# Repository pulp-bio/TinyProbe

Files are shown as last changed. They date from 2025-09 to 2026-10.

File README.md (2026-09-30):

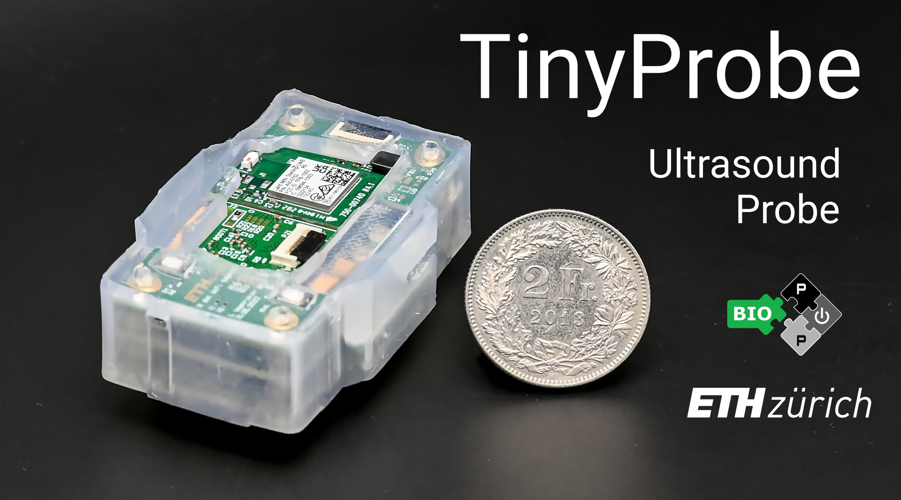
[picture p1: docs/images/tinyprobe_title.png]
TinyProbe main


# TinyProbe

A Wearable 32-Channel Multi-Modal Wireless Ultrasound Probe

## Introduction

This repository contains ongoing work on **TinyProbe**, an advanced wearable ultrasound platform developed at the [Integrated Systems Laboratory (IIS)](https://iis.ee.ethz.ch/) of ETH Zurich.

### Transmit

- **64 V peak-to-peak** bipolar excitations
- **32 pattern profiles** (fully programmable)
- **16 delay profiles** (fully programmable)

### Receive

- **21, 18, or 15 dB** low-noise amplifier (programmable)
- **21, 24, or 27 dB** programmable gain amplifier (PGA)
- **Up to 36 dB TGC** (fully programmable)
- **32 channels** (simultaneously sampled at up to **30 MSps, 10 bit**)

### Connectivity

Wi-Fi 6 link, data rates up to **35.7 Mbps**

### Operating Modes

1. **A-mode**, **B-mode**, **M-mode** with 32 channels (**175 FPS with Wi-Fi 6**, 32 channels, 400 samples per channel)
2. **Doppler mode** with 2 channels (**1500 FPS**)
3. **Raw RF data streaming** (**55 FPS**, 32 channels, 2000 samples per channel, 10 bit per sample)

The system design is described in detail in our publications in the [IEEE Transactions on Ultrasonics, Ferroelectrics, and Frequency Control (TUFFC)](https://ieeexplore.ieee.org/document/10750870), and in the [Proceedings of the IEEE International Ultrasonics Symposium (IUS 2025)](https://ieeexplore.ieee.org/abstract/document/11201780).

Please also take a look at our overview video on YouTube:

<a href="https://www.youtube.com/watch?v=qGP9-kKss0g">
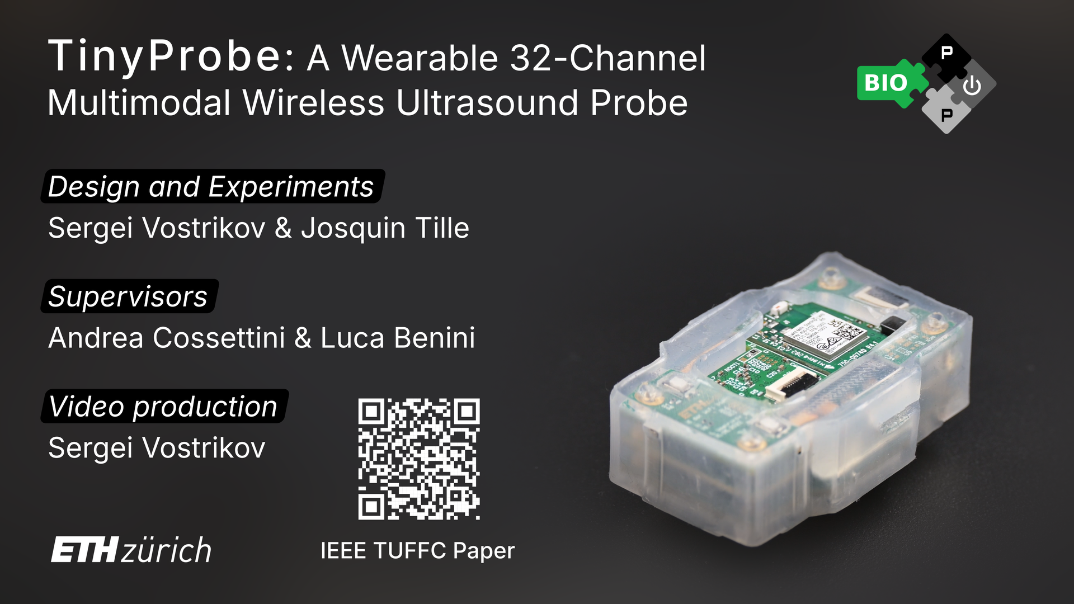
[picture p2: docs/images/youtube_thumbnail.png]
YouTube thumbnail
  
</a>

## Contents

Host software, MCU firmware, and board hardware are in this repository. FPGA gateware is planned for a later release.

```mermaid
flowchart TB
    Host["Host computer<br/>tipy Python package · software/"]

    subgraph Probe["TinyProbe hardware · hardware/"]
        MCU["SiWG917 Wi-Fi 6 MCU<br/>Firmware · firmware/"]
        FPGA["IGLOO 2 FPGA<br/>Gateware · release planned"]
        Analog["Analog front end and pulser<br/>AFE5832LP + TX7332"]

        MCU <-->|"SPI · control and captured data"| FPGA
        FPGA -->|"Configuration, clocks and triggers"| Analog
        Analog -->|"LVDS · receive data"| FPGA
    end

    Host <-->|"Wi-Fi · commands and RF data"| MCU

    style FPGA stroke-dasharray: 5 5
```

See the [hardware overview](hardware/README.md) for individual boards and their interconnections.

```bash
.
├── software/               # Host Python package, demos, and tests
├── firmware/               # SiWG917 Wi-Fi 6 MCU firmware
├── hardware/               # Board PCB designs
│   ├── wifi_board/         # Wi-Fi 6 PCB
│   ├── hv_board/           # Pulser PCB
│   └── acquisition_board/  # Acquisition board and its power-fix board
├── container/              # Docker and Apptainer firmware toolchain
├── config/                 # Description files for methods and register maps
├── docs/                   # Documentation files (Markdown, images, mkdocs)
└── licenses/               # Hardware, software, and image licenses
```

## Development

This repository uses [`uv`](https://docs.astral.sh/uv/) and [`just`](https://github.com/casey/just) for Python dependency and tool management. `just` is also included in the Python environment for convenience.

You can run `just` from the project root to see all available targets:

```bash
uv run just # Without activating Python environment
just # After activating Python environment / Using native binary
```

There is a [root workspace](pyproject.toml) at the project root as well as a [host project](software/pyproject.toml) project in the software directory.

The root workspace installs the host project in editable mode, so host development commands can also be run from the repository root.

### Dependency groups

You may not always need all of the dependencies, which is why there are multiple [dependency groups](https://docs.astral.sh/uv/concepts/projects/dependencies/#dependency-groups) with their own set of packages.

#### Root Workspace

| Group | Purpose |
| --- | --- |
| base | `just` and the host project |
| `dev` | Code generation and pre-commit hooks ([`embgen`](https://github.com/CedricHirschi/embgen), [Protocol Buffers](https://protobuf.dev/), [`prek`](https://prek.j178.dev/)) |
| `doc` | Documentation generation and serving ([Material for MkDocs](https://squidfunk.github.io/mkdocs-material/)) |

To install all of dependencies, run:

```bash
uv sync --group dev --group doc
```

#### Host Project

| Group | Purpose |
| --- | --- |
| base | Core dependencies for all functionalities |
| `dev` | Tests, linting, and type checking ([`pytest`](https://docs.pytest.org/en/stable/), [`ruff`](https://docs.astral.sh/ruff/), [`ty`](https://docs.astral.sh/ty/)) |
| `demo` | Demonstration and visualization ([`matplotlib`](https://matplotlib.org/)) |

To install all of dependencies, run:

```bash
cd software
uv sync --group dev --group demo
```

## Documentation

The MkDocs documentation in `docs/` starts with a system overview, followed by host software and Wi-Fi 6 firmware references. New
contributors should begin with the system overview to understand how the host,
MCU, FPGA, AFE, and TX paths fit together. Build or serve the site locally from
the repository root:

```bash
just docs_serve
```

## Citation

If you would like to reference the TinyProbe project, please cite:

```
@article{vostrikov2024tinyprobe,
  title={TinyProbe: A wearable 32-channel multi-modal wireless ultrasound probe},
  author={Vostrikov, Sergei and Tille, Josquin and Benini, Luca and Cossettini, Andrea},
  journal={IEEE Transactions on Ultrasonics, Ferroelectrics, and Frequency Control},
  year={2024},
  publisher={IEEE}
}
```

If you would like to reference only the Wi-Fi 6 PCB design, please cite:

```
@inproceedings{hirschi2025high,
  title={High Frame Rate Arterial Monitoring via Wi-Fi 6 on a 32-channel Wearable Ultrasound Probe},
  author={Hirschi, Cédric and Vostrikov, Sergei and Cossettini, Andrea and Benini, Luca},
  booktitle={2025 IEEE International Ultrasonics Symposium (IUS)},
  pages={1--4},
  year={2025},
  organization={IEEE}
}
```

## Authors

The TinyProbe system was developed at the [Integrated Systems Laboratory (IIS)](https://iis.ee.ethz.ch/) at ETH Zurich by:

- [Sergei Vostrikov](https://scholar.google.com/citations?user=a0KNUooAAAAJ) (Full-stack TinyProbe design)
- [Cédric Hirschi](https://scholar.google.com/citations?user=GRiRvUQAAAAJ) (Wi-Fi 6 Hardware development, Firmware & Software development)
- [Federico Villani](https://scholar.google.com/citations?user=5LgLMCEAAAAJ) (Hardware development)
- [Andrea Cossettini](https://scholar.google.com/citations?user=d8O91jIAAAAJ) (Supervision, project administration)
- [Luca Benini](https://scholar.google.com/citations?hl=en&user=8riq3sYAAAAJ) (Supervision, project administration)

Thanks to all the people who contributed to the TinyProbe platform:

- [Josquin Tille](https://scholar.google.com/citations?user=fLvAndoAAAAJ) (Silicone Package, Adapter PCB design)
- [Soumyo Bhattacharjee](https://scholar.google.com/citations?user=m5mJcRIAAAAJ) (Gateware, Firmware QSPI development)

## License

This repository makes use of the following licenses:

- for all *hardware* (`hardware/`): [Solderpad Hardware License Version 0.51](licenses/LICENSE.hw)
- for all *software* (`software/`): [Apache License Version 2.0](licenses/LICENSE.sw)
- for all *images* (`docs/images/`): [Creative Commons Attribution 4.0 International License](licenses/LICENSE.images)

For further information, please refer to the license files: `licenses/LICENSE.hw`, `licenses/LICENSE.sw`, `licenses/LICENSE.images`.

The `firmware/` and `software/` directories contain third-party sources that come with their own licenses. See their respective [README](firmware/README.md) and [README](software/README.md) for more information.

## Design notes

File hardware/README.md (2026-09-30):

# TinyProbe Hardware

This directory contains the PCB projects of the TinyProbe project. It includes the schematics, layouts and production files.

## Contents

```bash
hardware/
├── acquisition_board/      # Acquisition board (FPGA & AFE)
│   ├── acquisition_board/  # Main acquisition board project
│   └── power_fix_board/    # Power fix board project
├── hv_board/               # Pulser board project (Helios-T)
└── wifi_board/             # Wi-Fi 6 board project
```

The boards are connected as shown in the diagram below.

```mermaid
flowchart TB
    subgraph tinyprobe["TinyProbe"]
        direction TB
        subgraph wifi["Wi-Fi PCB"]
            mcu["SiWG917<br/>Wi-Fi 6 MCU"]
        end

        subgraph acquisition["Acquisition PCB"]
            fpga["IGLOO 2<br/>FPGA"]
            afe["AFE5832<br/>Analog Front End"]
        end

        subgraph hv["HV PCB"]
            pulser["TX7332<br/>±32 V Pulser"]
        end

        mcu <-->|SPI| fpga
        fpga -->|SPI| afe
        afe -->|LVDS| fpga
        fpga -->|SPI| pulser
        afe --- pulser
    end

    pulser <-->|32 channels| transducer["Transducer"]
```

## Errata

### Power Fix Board

Due to a minor mistake in the power architecture of the original acquisition board, a separate power fix board (`acquisition_board/power_fix_board`) was designed to correct the issue. This board needs to be soldered onto the main acquisition board to ensure proper power distribution.

## Sources

Sources referenced can be found in the [sources.md](sources.md) file.

## License

The hardware designs in this directory are licensed under the [Solderpad Hardware License Version 0.51](../licenses/LICENSE.hw)

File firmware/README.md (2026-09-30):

# TinyProbe Firmware

This directory contains the firmware for the SiWG917 Wi-Fi 6 MCU used in TinyProbe.

## Requisites

In order to use this firmware, you need to install Simplicity Studio. To get an introduction, check the [Toolchain Getting Started][toolchain_getting_started] guide.

Additionally, make sure you have the dependencies installed as described in the [Development section of the main README](../README.md#development).

**Note:** Using a container is the recommended way to build and flash the firmware, as it ensures a consistent development environment across different systems. See the [Containerized Development](#containerized-development) section for more information.

## Build and Flash Instructions

**Note:** These instructions assume you have made your way through the [Toolchain Getting Started][toolchain_getting_started] guide and have set up the example project as described there.

In order to build and flash the firmware, we will simply use the provided Justfile. This way, we circumvent the need to use Simplicity Studio directly, which does not work well on some systems.

From this directory, `just` lists the available recipes. To build:

```bash
just build
```

### Environment Variables

You will see the following error:

```bash
FileNotFoundError: [Errno 2] No such file or directory: '.env'
```

This project includes some sensitive information that is included at build time and that should not be committed to version control. To proceed, you need to provide this information in a safe(ish) way.

The project expects Wi-Fi credentials:

- `WIUS_WIFI_SSID`: Wi-Fi network name
- `WIUS_WIFI_PASS`: Wi-Fi password

Create a `.env` file in this directory:

```bash
WIUS_WIFI_SSID=<your_wifi_ssid>
WIUS_WIFI_PASS=<your_wifi_password>
```

`just build` generates `user/env.h` from this file. Do **not** commit `.env` or `user/env.h`.

### Building

If the CMake project files have not been generated yet (for example after a fresh clone), run:

```bash
just generate
```

Then build:

```bash
just build
```

This should build the project without errors. The resulting firmware binary will be located at `cmake_gcc/build/base/fw_v6.hex`.

### Flashing

To flash the firmware to the device, connect it via USB and run:

```bash
just flash
```

**Note:** On Linux, you need to install the udev rules for the board to be recognized. Please refer to the [Toolchain Getting Started][toolchain_getting_started] guide for more information.

### Monitoring

To monitor the logging output of the device, attach via RTT:

```bash
just attach       # Attach without resetting the device
just attach_reset # Attach with a device reset
```

### Cleaning

```bash
just clean      # Remove the CMake build directory and generated user/env.h
just clean_all  # Also remove SLC-generated files and config files except pin_config.h
```

## Code Structure

`config/pin_config.h` is a header containing the WiUS SSI and GSPI pin assignments. Keep it in source control and preserve it when cleaning or regenerating SDK configuration files. Edit board pin assignments in this header rather than replacing it with Pin Tool output.

The application code is in the `user` directory, divided into the following directories:
- `user/wius`: Low-level and Hardware-specific code for the WiUS PCB
  - Peripheral drivers
  - Networking drivers
  - etc.
- `user/tp`: TinyProbe-specific code built on top of the WiUS code
  - Power Management
  - AFE/TX drivers (pre-compiled)
  - Command handlers
  - etc.
- `user/common`: Other, common code that is used by both WiUS and TinyProbe
  - common.h / common.c: Common code that is used by both WiUS and TinyProbe
  - log.h / log.c: Logging code
  - led.h / led.c: LED control code
- `user/config.h`: Constants and configuration code
- `user/user.h`/`user/user.c`: User entry point for the firmware

## Containerized Development

A self-contained firmware toolchain is provided under [`../container/`](../container). See [that README](../container/README.md) for prerequisites (including the SLT installer zip), recipe details, and Dev Container setup.

### Docker

**Note:** Tested on Windows 11 with WSL 2.

```bash
cd ../container
just build
just run
```

### Apptainer

**Note:** Tested on ETH IIS Alma Linux clients.

```bash
cd ../container
just build_appt
just run_appt
```

From the repository root you can also use `just container run` / `just container run_appt`.

Inside the container, continue with the build steps above (`just generate`, `just build`, etc.).

## Licensing

The firmware written at the [Integrated Systems Laboratory (IIS)](https://iis.ee.ethz.ch/) (ETH Zurich) is licensed under the [Apache License 2.0](../licenses/LICENSE.sw). That is the code under `user/`, plus `main.c` and `config/pin_config.h`.

This directory does not include the Silicon Labs Simplicity SDK or the WiseConnect 3 SDK. Install them locally (see the [Toolchain Getting Started][toolchain_getting_started] guide, or use the container under `../container/`), then run `just generate`. That step writes SDK sources and generated headers such as `sl_board_configuration.h` into this tree. They are covered by the [Master Software License Agreement](https://www.silabs.com/about-us/legal/master-software-license-agreement) and the corresponding license conditions apply.

[nanopb](https://github.com/nanopb/nanopb) is vendored under `vendor/nanopb` and is licensed under the [Zlib License](https://github.com/nanopb/nanopb/blob/master/LICENSE.txt).

### AFE5832LP and TX7332 drivers

The drivers for the [AFE5832LP](user/tp/hal/tp_afe.h) and [TX7332](user/tp/hal/tp_tx.h) are included in this repository as precompiled binaries; source code for these drivers is not released as distribution restrictions apply.

[toolchain_getting_started]: ../docs/firmware/toolchain.md

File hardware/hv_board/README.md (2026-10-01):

# TinyProbe Pulser Board PCB Project

The Altium project of this PCB is available for download from [here](https://iis-people.ee.ethz.ch/~pulp-bio/TinyProbe/tp_hv_board_v2.zip).

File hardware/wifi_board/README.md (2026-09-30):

# WiUS Hardware

This directory contains the Altium hardware design files for the WiUS project. It follows the default Altium project structure.

The schematics and assembly drawings are also available in PDF format:
- [Schematics](docs/wius_schematics.pdf)
- [Assembly](docs/wius_assembly.pdf)

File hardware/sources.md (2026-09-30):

# TinyProbe Hardware References

During the development of the TinyProbe hardware, the following sources of information provided component pinouts and footprints. Limitation of liability and accuracy should be considered when using these sources.

## SiWG917

Pinout and footprint: [SiWG917 Datasheet](https://www.silabs.com/documents/public/data-sheets/siwg917-datasheet.pdf) (Accessed: 25.09.2026)

## IGLOO 2

Footprint: [IGLOO 2 Packaging and Pin Descriptions User Guide](https://www.microchip.com/content/dam/mchp/documents/FPGA/ProductDocuments/SoC/m2gl_ds0124_pin_info_v6.pdf) (Accessed: 25.09.2026)

Pinout: [IGLOO 2 VF400 Pinouts](https://ww1.microchip.com/downloads/aemDocuments/documents/FPGA/ProductDocuments/SoC/igloo2_vf400_pinouts.zip) (Accessed: 25.09.2026)

## AFE5832

Pinout: [slou489 (TI)](https://www.mouser.com/datasheet/2/405/1/slou489-3395478.pdf) (Accessed: 25.09.2026)

Footprint: [AFE5832 Datasheet](https://www.ti.com/lit/ds/symlink/afe5832.pdf) (Accessed: 25.09.2026)

AFE5832 is pin-to-pin compatible with the AFE5832LP: [sbaa297 (TI)](https://www.ti.com/lit/ab/sbaa297/sbaa297.pdf) (Accessed: 25.09.2026)

## TX7332

Pinout: [sbor18 (TI)](https://www.ti.com/lit/df/sbor018/sbor018.zip) (Accessed: 20.08.2025)

Footprint: [TX7332 Datasheet](https://www.ti.com/lit/ds/symlink/tx7332.pdf) (Accessed: 25.09.2026)

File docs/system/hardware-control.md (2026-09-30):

# Hardware And Control Overview

The MCU owns the low-speed control plane. It receives host commands over Wi-Fi,
selects the correct SPI destination, controls board power domains, and reads
captured FPGA data for UDP streaming.

## SPI Multiplexing

Firmware exposes four SPI mux selections in `tp_mux_t`:

| Firmware target | Enum value | `TP_MUX_GPIO_EXTINT` | `TP_MUX_GPIO_AFETX` | Use |
| --- | --- | --- | --- | --- |
| PLL | `TP_MUX_PLL` / `0b00` | Low | Low | Low-speed PLL mux state defined by the board control path. |
| FPGA | `TP_MUX_FPGA` / `0b01` | Low | High | MCU talks to the internal FPGA SPI slave. |
| AFE | `TP_MUX_AFE` / `0b10` | High | Low | MCU SPI is forwarded to the AFE SPI chip select. |
| TX | `TP_MUX_TX` / `0b11` | High | High | MCU SPI is forwarded to the TX SPI chip select. |

## MCU To FPGA

When the mux selects `TP_MUX_FPGA`, the MCU talks to the FPGA SPI slave. The
firmware driver uses these command bytes:

| Command | Value | Purpose |
| --- | --- | --- |
| `SPI_READ_CFG` | `1` | Read the FPGA SPI configuration byte. |
| `SPI_WRITE_CFG` | `2` | Write the FPGA SPI configuration byte. |
| `SP_RD_FIFO` | `16` | Read data from the FPGA FIFO path. |
| `SPI_WR_FIFO` | `17` | Write command/control words into the FPGA SPI slave. |

FPGA register access is layered on top of `SPI_WR_FIFO`. A register write sends
the memory-controller write command, the register address, and the 32-bit value.
`tp_fpga_write_reg_safe()` writes the value, sends a NOP, reads the FIFO path,
issues a read-register command, reads the value back, and compares it.

The firmware also uses system-controller command values through register address
0: start acquisition, reset the multififo, enable readout, and echo. Trigger
shot handling resets the FPGA multififo, optionally sends start, waits for the
configured FPGA interrupt source, enables readout, then reads FIFO packets.

## FPGA To AFE And TX

The FPGA communicates with AFE and TX in two ways:

| Path | Direction | Purpose |
| --- | --- | --- |
| Forwarded SPI | MCU through FPGA pins to AFE/TX | Programs AFE and TX registers. |
| AFE clock | FPGA to AFE | Supplies the receive sampling clock when enabled. |
| AFE TX trigger | FPGA to AFE | Aligns receive-side behavior with the TX event. |
| AFE LVDS | AFE to FPGA | Carries receive data, frame clock, and bit clock. |
| TGC pins | FPGA to AFE | Drives TGC slope and direction. |
| AFE fast powerdown | FPGA to AFE | Duty-cycles AFE fast powerdown around the acquisition window. |
| TX BF clock | FPGA to TX | Supplies the TX beamformer clock when enabled. |
| TX BF sync | FPGA to TX | Triggers the TX timing profile. |
| TX TR_EN | FPGA to TX | Enables the transmit/receive switch path and periodic refresh behavior. |

## Programming AFE And TX

Programming an external analog device follows the same pattern:

1. Select `TP_MUX_AFE` or `TP_MUX_TX` in firmware.
2. Run the device-specific SPI initialization or register writes.
3. Select `TP_MUX_FPGA` again before FPGA register access or FIFO readout.
4. Start acquisition only after FPGA, AFE, TX, and power-domain state are
   coherent for the requested modality.

The startup flow in `tp_init()` follows this structure: reset FPGA, select FPGA
and configure defaults, enable board power domains, reset AFE/TX through FPGA
control, select TX and initialize it, select AFE and initialize it, then return
to the FPGA target before starting Wi-Fi command handling.

## MCU Power Responsibilities

The firmware power driver declares these TinyProbe power domains:

| Domain | Purpose |
| --- | --- |
| `TP_POWER_DOMAIN_LVDS_2_5V` | LVDS IO supply switch. |
| `TP_POWER_DOMAIN_POS_HV` | Positive high-voltage transmit rail. |
| `TP_POWER_DOMAIN_NEG_HV` | Negative high-voltage transmit rail. |
| `TP_POWER_DOMAIN_NEG_5V` | Negative 5 V analog rail. |
| `TP_POWER_DOMAIN_PLL_PWD` | Declared PLL power-down domain; currently logs not implemented in the firmware driver. |

Host acquisition flows use MCU control methods to turn these domains on before
shots and back off after acquisition. Some FPGA-controlled signals, such as AFE
fast powerdown and TX `TR_EN`, are timing signals rather than MCU GPIO power
domains.

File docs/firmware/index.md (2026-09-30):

# Firmware Overview

TinyProbe firmware runs on the Wi-Fi 6 MCU. It receives host commands, controls
the SPI mux, configures FPGA/AFE/TX devices, manages board power domains, waits
for FPGA acquisition events, reads captured data over SPI, and streams RF data
back to the host.

Start with the [system overview](../system/index.md) for the full acquisition
flow, then use [Hardware & Control](../system/hardware-control.md) for the MCU
control paths. The generated API pages below document the firmware modules.

We have the [common module](group__common.md), [WiUS module](group__wius.md), and [TinyProbe module](group__tinyprobe.md) documented here. These three modules have the following relationships:

```mermaid
graph TD
    A[Common Module]
    B[WiUS Module] --> A
    C[TinyProbe Module] --> A
    C --> B
```

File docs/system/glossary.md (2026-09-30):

# Glossary And Contributor Orientation

## Glossary

| Term | Meaning |
| --- | --- |
| AFE | Analog front end. In TinyProbe this is the AFE5832LP receive chip. |
| Acquisition | One configured run that may contain one or more ultrasound shots and RF data transfers. |
| Capture delay | Delay from the FPGA trigger point to the start of FIFO capture. |
| FIFO | First-in, first-out buffer in the FPGA used to hold captured RF samples until MCU readout. |
| FPGA | Field-programmable gate array. Generates timing, captures LVDS data, and buffers samples. |
| Gateware | The SystemVerilog design programmed into the FPGA. |
| Host | The PC running the `tipy` Python package. It configures acquisitions and receives data. |
| LVDS | Differential digital interface used by the AFE to send receive sample data and clocks to the FPGA. |
| MCU | Microcontroller on the Wi-Fi board. It owns Wi-Fi, SPI target selection, power GPIOs, and command handling. |
| Power domain | A controllable board supply such as positive HV, negative HV, negative 5 V, or LVDS 2.5 V. |
| Shot | One transmit/receive event inside an acquisition. |
| Sync period | FPGA waveform-generator period between trigger opportunities. |
| TGC | Time gain compensation. A gain ramp applied during receive to compensate depth-dependent attenuation. |
| TX BF | Transmit beamformer. In TinyProbe this refers to TX7332 timing and pulse control. |

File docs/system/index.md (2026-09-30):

# TinyProbe System Overview

TinyProbe is a wireless ultrasound research platform split across host software,
MCU firmware, FPGA gateware, and analog front-end hardware. Start here when you
need the whole system model before working on one subsystem.

```mermaid
flowchart LR
    Host["Host PC<br/>tipy Python package"] -->|"TCP protobuf commands"| MCU["Wi-Fi 6 MCU<br/>TinyProbe firmware"]

    MCU -.->|"SPI mux: FPGA target"| FPGA["FPGA<br/>registers, timing, FIFO"]
    MCU -.->|"SPI mux: AFE target"| AFE["AFE5832LP<br/>receive front end"]
    MCU -.->|"SPI mux: TX target"| TX["TX7332<br/>transmit beamformer"]

    FPGA -->|"AFE clock, trigger, TGC, fast powerdown"| AFE
    FPGA -->|"TX BF clock, sync, TR_EN"| TX

    TX ==>|"HV excitation"| Probe["Transducer elements"]
    Probe ==>|"echoes"| AFE

    AFE -->|"LVDS data, frame clock, bit clock"| FPGA
    FPGA -->|"FIFO read over SPI"| MCU
    MCU -->|"UDP RF packets"| Host

    subgraph host ["Host PC"]
        Host
    end

    subgraph tinyprobe ["TinyProbe"]
        MCU
        FPGA
        AFE
        TX
    end

    subgraph transducer ["Transducer"]
        Probe
    end
```

## Main Components

| Component | Main responsibility | Where to look |
| --- | --- | --- |
| Host PC | Builds acquisition configs, writes AFE/TX/FPGA settings, receives RF data, and runs processing tools. | [Software](../software/index.md) |
| MCU firmware | Owns Wi-Fi command and bulk links, SPI target selection, power control, FPGA FIFO readout, and command handlers. | [Firmware](../firmware/index.md) |
| FPGA gateware | Generates shot timing, captures LVDS data, controls AFE/TX timing pins, and buffers RF samples. | _Future Open-Sourcing_ |
| AFE5832LP | Receives analog echo signals, applies gain/TGC, digitizes data, and emits LVDS streams. | [Hardware & Control](hardware-control.md) |
| TX7332 | Generates transmit pulses and beamforming delays for the probe elements. | [Hardware & Control](hardware-control.md) |

## Control And Data Flow

The host software is the top-level control point. A measurement protocol such as
`tipy.protocol.example` prepares FPGA timing, AFE receive settings,
TX pulse settings, power commands, and a trigger-shot request. These commands
are sent to the MCU over the TCP command interface.

The MCU receives framed protobuf commands, selects the required SPI destination,
and performs the low-speed configuration transactions. FPGA register writes use
the FPGA SPI slave. AFE and TX programming uses the same MCU SPI peripheral, but
the firmware changes the mux state so the transaction reaches the selected
external device.

During acquisition, the FPGA is responsible for precise timing. It emits trigger
and clock/control signals to the TX and AFE, receives LVDS sample data from the
AFE, writes samples into its RX FIFO, and exposes the FIFO through the SPI slave.
The MCU waits for the selected FPGA interrupt event, reads the FIFO over SPI, and
sends RF data packets back to the host over UDP.

## One Acquisition

A typical ultrasound acquisition follows this sequence:

1. The host creates a modality configuration: enabled LVDS lanes, sample count,
   shot period, AFE gain/TGC settings, TX pulse profile, and timing delays.
2. The host sends register and method commands to the MCU.
3. The MCU initializes or updates FPGA, AFE, and TX state by selecting the
   correct SPI target for each transaction.
4. The host powers on the required rails through MCU control methods. Common
   domains include positive high voltage, negative high voltage, negative 5 V,
   and the LVDS IO supply.
5. The host sends a trigger-shot command. For a software-triggered acquisition,
   the MCU writes the FPGA start command.
6. The FPGA waveform generator aligns the shot to its internal period, emits the
   TX/AFE trigger at the trigger point, enables the relevant clocks and
   powerdown signals, and opens the FIFO write window.
7. The AFE digitizes receive data and sends LVDS data, frame clock, and bit
   clock to the FPGA.
8. The FPGA writes the selected data window into the RX FIFO and raises the
   configured MCU interrupt source.
9. The MCU enables readout, reads FIFO data over SPI, packetizes it, and sends
   UDP bulk packets to the host.
10. The host reassembles and parses the RF data for saving, plotting, or further
    ultrasound processing.

For deeper subsystem detail, continue with [Hardware & Control](hardware-control.md) and [Acquisition Timing](acquisition-timing.md).

## Where To Start

| Track | Start here | Then inspect |
| --- | --- | --- |
| System behavior | [System Overview](index.md) | [Acquisition Timing](acquisition-timing.md) |
| Host software | [Software Overview](../software/index.md) | `software/` |
| Firmware | [Firmware Overview](../firmware/index.md) | `firmware/`, especially methods and HAL drivers |
| Gateware | _Future Open-Sourcing_ | _Future Open-Sourcing_ |
| Hardware control | [Hardware & Control](hardware-control.md) | Firmware mux/power drivers and FPGA SPI demux logic |

## Traceability Hints

Most TinyProbe features cross subsystem boundaries. When adding a feature, trace
the setting through the stack:

1. Host config field or HAL property.
2. Protobuf command or register write.
3. MCU method handler and SPI mux target.
4. FPGA register, external AFE/TX register, or MCU power GPIO.
5. Timing signal, data path, or returned UDP packet format.

This trace keeps feature work local while making the system-level side effects
explicit.

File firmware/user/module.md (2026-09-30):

@defgroup common Common Module
@brief Shared utilities, HAL glue, and logging used across TinyProbe and WiUS

# Common Module

The common module provides shared glue that both @ref tinyprobe "TinyProbe" and @ref wius "WiUS" modules rely on. It contains lightweight utilities, logging, timing helpers, and macros that keep the platform code consistent across commands and transports.

## Purpose
- Provide common macros and helpers (see @ref common.h)
- Offer a lightweight logging facade for all modules (see @ref log.h)
- Centralize timing/delay helpers used by command handlers and drivers

## Key Pieces
- Logging: initialized via `log_init()` and consumed through `LOG_*` macros
- Time helpers: `delay_ms`, `delay_ns`, and `TICKS_PER_SEC` definitions
- Safety macros: `CHECK_STATUS`, `ASSERT`, and argument extraction helpers in commands

## Interactions
- Method handlers in @ref tinyprobe_methods "TinyProbe Methods" use the logging and argument macros from this module.
- WiUS transports depend on shared type and error definitions.

@addtogroup common
@{
@}

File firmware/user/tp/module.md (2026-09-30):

@defgroup tinyprobe TinyProbe Module
@brief Method processing, FPGA/AFE control, and probe orchestration

# TinyProbe Module

TinyProbe translates incoming control messages into hardware actions on the probe. It owns the method registry, FPGA/AFE access, and buffers that feed outbound data paths.

## Architecture

- Method dispatch: protobuf request decoding and routing in @ref tp_methods.h
- Method handlers: grouped under @ref tinyprobe_methods "TinyProbe Methods" with one handler per generated method
- Hardware control: FPGA, AFE, TX, mux, and power accessors in @ref tp_fpga.h, @ref tp_afe.h, @ref tp_tx.h, @ref tp_mux.h, and @ref tp_power.h
- Buffering: circular buffer helpers in @ref tp_buffer.h

## Data Flow (high level)

1. WiUS transport receives a message and forwards it to the TinyProbe method layer.
2. `tp_methods_handle()` decodes the nanopb request and selects the matching handler from @ref tinyprobe_methods "TinyProbe Methods".
3. Handlers perform register writes/reads through TinyProbe helpers and may enqueue data into probe buffers.
4. Status replies are encoded as protobuf responses and returned via the WiUS transport.

## Extending TinyProbe

- Add a new method: update the generated method definition, create `tp_method_<name>.c/.h`, add it to `TP_METHODS`, and document it under @ref tinyprobe_methods "TinyProbe Methods".
- Touch hardware safely: prefer helper APIs in `tp_fpga`, `tp_afe`, `tp_tx`, `tp_mux`, and `tp_power` rather than open-coded register writes to keep side effects contained.

@addtogroup tinyprobe
@{
@}

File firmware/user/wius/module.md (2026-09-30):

@defgroup wius WiUS Module
@brief Wireless transport, sockets, and power coordination for TinyProbe

# WiUS Module

The WiUS module handles connectivity, sockets, and power states for the probe. It exposes TCP/UDP helpers that feed TinyProbe's command pipeline and provides GPIO/SPI abstractions used by the hardware-facing code.

## Responsibilities

- Networking: TCP server and UDP helpers in @ref wius_tcp.h and @ref wius_udp.h
- Wi-Fi control: initialization and mDNS helpers in @ref wius_wifi.h
- Peripheral access: GPIO and SPI wrappers in @ref wius_gpio.h and @ref wius_spi.h
- Power: power mode helpers in @ref wius_power.h

## Interaction with TinyProbe

- Incoming network packets are delivered to the @ref tinyprobe "TinyProbe" dispatcher along with metadata required for replies.
- Command replies (when enabled) are sent back via WiUS TCP/UDP primitives.
- Power state transitions should be coordinated so that active transfers are drained before entering low-power modes.

## Notes for Contributors

- Keep socket buffer sizes and queue depths in sync with command expectations to avoid partial frames.
- When adding transports or altering power behavior, document the flow here and cross-reference the affected command handlers.

@addtogroup wius
@{
@}

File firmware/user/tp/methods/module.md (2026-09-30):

@defgroup tinyprobe_methods TinyProbe Methods
@ingroup tinyprobe
@brief Method handlers for TinyProbe control operations

# TinyProbe Methods

This group contains all method handlers used by TinyProbe to interact with hardware and system services. Each method implementation and its public interface lives in this subgroup to keep the method surface easy to navigate.

## Method Catalog

| Method | Header | Description |
|---|---|---|
| Ping | @ref tp_method_ping.h | Reachability and identity check |
| Trigger shot | @ref tp_method_triggershot.h | Trigger capture |
| Delay ns | @ref tp_method_delayns.h | Nanosecond timing control |
| Delay ms | @ref tp_method_delayms.h | Millisecond timing control |
| Power control | @ref tp_method_controlpower.h | Toggle power rails |
| Set log level | @ref tp_method_setloglevel.h | Configure firmware log verbosity |
| SPI MUX | @ref tp_method_controlspi.h | Select SPI MUX target |
| Write AFE | @ref tp_method_writeafe.h | AFE register write |
| Write FPGA | @ref tp_method_writefpga.h | FPGA register write |
| Write TX | @ref tp_method_writetx.h | TX buffer write |

## How Methods Are Dispatched

1. Incoming framed protobuf packets are decoded by `tp_methods_handle()` in @ref tp_methods.h.
2. The dispatcher switches on the generated nanopb oneof tag and calls the corresponding handler from this group.
3. Handlers validate arguments, perform hardware actions through @ref common "common" helpers and TinyProbe drivers, and return a generated status code.

## Adding a New Method

- Create `tp_method_<name>.c/.h` under `user/tp/methods/`.
- Add it to the generated method definition and include it in the `TP_METHODS` macro.
- Document it in this catalog and keep the description concise (what it does, inputs, side effects).

@addtogroup tinyprobe_methods
@{
@}

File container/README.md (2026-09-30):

# TinyProbe Development Containers

The containers provide a fully self-contained firmware build environment for the SiWG917 target.
They bundle the Silicon Labs toolchain: `slt`, `slc`, `cmake`, `ninja`, ARM GCC 12.2, `commander`, `sdm`, Simplicity SDK 2025.6.2, and WiseConnect 3.5.2, so no host-side Silicon Labs installation is required.

Two container formats are provided:

| Format | File | Use case |
|---|---|---|
| Docker | `Dockerfile` | Local development, CI/CD |
| Apptainer (Singularity) | `container.def` | HPC clusters, rootless environments |

All recipes are managed with `just`. Run `just` from this directory to list them.

## Prerequisites

### SLT installer zip (both formats)

The Silicon Labs `slt-cli` installer is not redistributed in this repository.
Download `slt-cli-1.0.1-linux-x64.zip` from [Silicon Labs](https://www.silabs.com/documents/public/software/slt-cli-1.0.1-linux-x64.zip) directly
and place it next to the `Dockerfile` / `container.def` before building:

```
container/
├── slt-cli-1.0.1-linux-x64.zip  # place here
├── Dockerfile
├── container.def
└── ...
```

## Quick start

### Docker

```bash
# Build the image (once)
just build

# Run a shell with the firmware directory mounted
just run

# Run with a custom directory
just run /path/to/your/dir
```

### Apptainer

```bash
# Build the SIF image (once, needs the zip next to container.def)
just build_appt

# Open a shell with the repo root bound into the container
just run_appt

# Run with a custom directory
just run_appt /path/to/your/dir
```

## Available recipes

```
build        Build the Docker image
build_appt   Build the Apptainer SIF image
pack         Export the Docker image to a gzipped tarball
load         Import a previously packed Docker image tarball
run          Run a Docker shell with the firmware directory mounted
run_appt     Open an Apptainer shell with the repo root bound
publish      Tag and push the Docker image to Docker Hub
```

## Installed toolchain

The build environment installs the following via `slt` (`cli_tools.toml`):

| Tool | Version |
|---|---|
| cmake | latest |
| commander | latest |
| gcc-arm-none-eabi | 12.2.rel1 |
| ninja | latest |
| sdm | latest |
| simplicity-sdk | 2025.6.2 |
| slc\_cli | latest |
| wiseconnect | 3.5.2 |

After installation `PATH`, `ARM_GCC_DIR`, `SLC_SDK`, and `POST_BUILD_EXE` are set automatically
so that `slc`, `cmake`, `ninja`, and `commander` are available in every shell session.

## Docker Hub

To publish the Docker image to Docker Hub:

```bash
just publish <your-dockerhub-username>
# or with a custom image name
just publish <your-dockerhub-username> my-image-name
```

## Dev Containers (VS Code / Cursor)

Both container flavours can be used as a Dev Container.

### Docker

Add a `.devcontainer/devcontainer.json` in the repository root that points to this `Dockerfile`:

```json
{
  "name": "TinyProbe firmware",
  "build": { "context": "container", "dockerfile": "container/Dockerfile" },
  "workspaceMount": "source=${localWorkspaceFolder}/firmware,target=/work,type=bind",
  "workspaceFolder": "/work"
}
```

### Apptainer

Add the following to `~/.ssh/config` to add an SSH configuration for the Apptainer container:

```
Host tinyprobe-apptainer
  HostName <your hostname>
  User <your username>
  RemoteCommand cd /path/to/this/repo && just container run_appt
  RequestTTY yes
```

Check if the configuration is working by trying to SSH into the container:

```bash
ssh tinyprobe-apptainer
```

If you see a `Apptainer>` prompt, the configuration is working.

Now, we need to set a global setting in VS Code to allow the container to install the VS Code server. Open the Command Palette (Ctrl+Shift+P) and search for "Preferences: Open User Settings (JSON)". Add the following settings:

```json
"remote.SSH.enableRemoteCommand": true,
"remote.SSH.serverInstallPath": {
    "apptainer": "/path/to/this/repo/.vscode_server"
}
```

You can now use the container as a Dev Container in VS Code by connecting to `tinyprobe-apptainer` via SSH. See [VS Code Remote - SSH](https://code.visualstudio.com/docs/remote/ssh#_connect-to-a-remote-host) for details. In short: Open command palette, search for "Remote-SSH: Connect to Host...", and select `tinyprobe-apptainer`. The container will be started and the VS Code server will be installed automatically.

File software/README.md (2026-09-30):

# TinyProbe Software

This directory contains the software side of the TinyProbe project. It consists of a Python package, as well as some demo code and thorough unit tests.

## Contents

```bash
software/
├── src/tipy/       # Host Python package
│   ├── control/    # RPC commands, bulk transfer, and protobuf methods
│   ├── hardware/   # FPGA register map and hardware abstraction layer
│   ├── protocol/   # Acquisition protocols and example configurations
│   ├── runtime/    # Device session and received-data parsing
│   ├── tools/      # HDF5 saving, mDNS discovery, logging, and schema generation
│   └── transport/  # Framed link over UDP, TCP, or a dummy implementation
├── demo/           # Example scripts that exercise the package
├── test/           # Unit tests and recorded acquisition fixtures
└── schemas/        # Generated JSON schemas for protocol configs
```

### `src`

`src/tipy` is the host package. `control` sends protobuf RPC commands and receives bulk data. `transport` frames that link over UDP, TCP, or a dummy implementation. `hardware` is the FPGA register map and the abstraction used to write it. `protocol` turns a configuration into setup, acquire, and teardown steps. `runtime` holds the device session and parses received samples. `tools` covers HDF5 saving, mDNS discovery, logging, and schema generation.

### `demo`

Scripts here call the package the way a host application would. `demo_acquisition.py` runs the example protocol from `demo_acquisition.json`. The other scripts are smaller entry points for one area each: `control/` (commands, RPC, and bulk receive), `hardware/` (register map and FPGA HAL), `protocol/`, `runtime/` (session and parser, with an example bitstream), and `tools/` (mDNS and HDF5 saving). Several of them need the `demo` dependency group for matplotlib.

### `test`

`test/` is the pytest suite. Each `test_*.py` file covers one part of the package: the session, parser, protocol, FPGA HAL, register map, RPC server, transports, and HDF5 saving. `data/` holds recorded acquisitions (`acquisition_20260404_002003` and `string_1cm`) used by the saving tests. `common.py` holds fixtures shared by those tests.

## Just targets

Recipes are defined in [`Justfile`](Justfile). Run them from this directory, or from the repository root as `just software <target>`.

The test and lint recipes need the `dev` dependency group:

```bash
uv sync --group dev
```

| Target | What it does |
| --- | --- |
| `test` | Run the pytest suite |
| `lint` | Format, lint, and typecheck |
| `format` | Format with ruff |
| `check` | Lint with ruff, applying fixes |
| `typecheck` | Typecheck with ty |
| `schemas` | Regenerate the JSON schemas in `schemas/` |

`just` with no arguments lists these recipes.

## Using the package

`tipy` requires Python 3.13 or newer. The installable project is this `software/` directory. Add it with [`uv`](https://docs.astral.sh/uv/) from a directory on disk, from a git submodule, or directly from the repository.

### Directory

Point uv at a checkout you already have. An editable install follows later edits in that checkout:

```bash
uv add --editable ./path/to/tinyprobe/software
```

uv records the source in `pyproject.toml`:

```toml
[project]
dependencies = ["tipy"]

[tool.uv.sources]
tipy = { path = "path/to/tinyprobe/software", editable = true }
```

This repository depends on `tipy` the same way: the root project sets `path = "software"`.

### Git submodule

Add the repository as a submodule, then depend on the `software/` directory inside it:

```bash
git submodule add https://github.com/pulp-bio/TinyProbe.git third_party/tinyprobe
uv add --editable ./third_party/tinyprobe/software
```

### Repository

Depend on the Git repository without a local checkout. `subdirectory` selects the `software/` project:

```bash
uv add "git+https://github.com/pulp-bio/TinyProbe.git#subdirectory=software" # Over HTTPS
uv add "git+ssh://git@github.com/pulp-bio/TinyProbe.git#subdirectory=software" # Over SSH
```

Pin a commit, tag, or branch with `--rev`, `--tag`, or `--branch`. The equivalent source entry is:

```toml
[project]
dependencies = ["tipy"]

[tool.uv.sources]
tipy = { git = "https://github.com/pulp-bio/TinyProbe.git", subdirectory = "software", rev = "<commit>" }
```

## License

The software in this directory is licensed under the [Apache License Version 2.0](../licenses/LICENSE.sw).

Files generated by [embgen](https://github.com/CedricHirschi/embgen) are under MIT license, as specified in [embgen's license](https://github.com/CedricHirschi/embgen/blob/main/LICENSE.md). These files include:

- [`src/tipy/control/methods.py`](src/tipy/control/methods.py)
- [`src/tipy/hardware/regmap_base.py`](src/tipy/hardware/regmap_base.py)
- [`src/tipy/hardware/fpga/regmap.py`](src/tipy/hardware/fpga/regmap.py)

Files generated by Protocol Buffers (`protoc`) are under the same license as Protocol Buffers itself, which is the [BSD 3-Clause License](https://github.com/protocolbuffers/protobuf/blob/main/LICENSE). These files include:

- [`src/tipy/control/methods_pb2.py`](src/tipy/control/methods_pb2.py)
- [`src/tipy/control/methods_pb2.pyi`](src/tipy/control/methods_pb2.pyi)

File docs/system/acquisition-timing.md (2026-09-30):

# Acquisition Timing

The FPGA waveform generator defines the timing of one shot period. It is clocked by the 10 MHz FPGA clock, so one RTL
counter cycle is 100 ns for that source. Host-side HAL code converts user-facing
microsecond settings into waveform-generator cycles.

## Timing Model

```mermaid
flowchart LR
    T0["counter = 0<br/>settings sampled"] --> TA["t_sync - afe_clk_on - afe_wake<br/>AFE clock on"]
    TA --> TB["t_sync - tx_wake<br/>TX clock and TR_EN on"]
    TB --> TC["t_sync - afe_wake<br/>AFE fast powerdown inactive"]
    TC --> TD["t_sync<br/>TX BF sync and AFE TX trigger"]
    TD --> TE["t_sync + capture_delay - 5<br/>FIFO reset pulse"]
    TE --> TF["t_sync + capture_delay<br/>FIFO start and write enable"]
    TF --> TG["t_sync + capture_delay + afe_data_acq<br/>FIFO write ends"]
    TG --> TH["t_sync + capture_delay + afe_data_acq + afe_wake<br/>AFE clock off"]
    TH --> TI["sync_period<br/>counter wraps"]
```

The trigger point is `t_sync = sync_period / 2`. A software start command does
not fire the trigger immediately; it arms the waveform generator, and the shot is
emitted on the next active period boundary.

## Timepoints And Windows

| Signal or timepoint | RTL relationship | Effect |
| --- | --- | --- |
| Settings sample | `counter == 0` | New timing inputs are latched for the next period. |
| Trigger point | `sync_period / 2` | `tx_bf_sync_o` and `afe_tx_trig_o` pulse when a shot is enabled. |
| TX clock window | `t_sync - tx_wake_up_time` through `t_sync + tx_sleep_time` | Enables the TX BF clock around the trigger. |
| TX `TR_EN` | `t_sync - tx_wake_up_time` through `t_sync` | Enables the TX path before the trigger. The inspected RTL drives this periodically, independent of shot enable. |
| AFE clock window | `t_sync - afe_clk_on_time - afe_wake_up_time` through `t_sync + capture_delay + afe_data_acq_time + afe_wake_up_time` | Keeps AFE clocks active before, during, and just after receive capture. |
| AFE fast powerdown inactive | `t_sync - afe_wake_up_time` through `t_sync + capture_delay + afe_data_acq_time` | Wakes the AFE for the active receive window. |
| FIFO reset | `t_sync + capture_delay - 5` | Clears the receive FIFO shortly before capture starts. |
| FIFO start capture | `t_sync + capture_delay` through `+ 4` cycles | Marks the beginning of the receive capture window and starts TGC timing. |
| FIFO write enable | `t_sync + capture_delay` through `t_sync + capture_delay + afe_data_acq_time` | Writes AFE LVDS words into the RX FIFO. |
| TGC timing | Starts from FIFO start capture plus configured TGC delays | Drives the AFE TGC slope and up/down pins. |

## Where Timing Values Come From

| User-facing setting | Host/firmware path | FPGA effect |
| --- | --- | --- |
| `shot_period_ms` / `meas_period_us` | Host FPGA HAL writes waveform sync period. | Sets the waveform-generator period and therefore the trigger spacing. |
| `num_shots` | Host HAL writes the shot-count field used by the configured flow. | Controls how many shots the acquisition command requests. |
| `fifo_depth` / `num_samples` | Host HAL writes the LVDS sample count and capture duration with margins. | Sets the expected FIFO depth and receive write window. |
| `lvds_lanes` | Host HAL writes the LVDS lane-enable mask. | Enables selected LVDS receive lanes when AFE clocks are active. |
| `afe_startcapt_delay_us` | Host HAL writes AFE capture start delay. | Moves FIFO reset/start/write relative to the trigger. |
| `tx_wakeup_us` and `tx_sleep_us` | Host HAL writes TX timing fields. | Changes TX clock and `TR_EN` windows around the trigger. |
| `afe_active_start_us` and `afe_active_duration_us` | Host HAL writes AFE timing fields. | Changes AFE clock and fast-powerdown timing around the receive window. |
| TGC settings | Host HAL writes TGC divider, start delay, capture time, and finish delay. | Controls TGC slope timing relative to capture start. |

## Required Timing Conditions

The waveform generator protects several inputs by applying defaults or clipping,
but a valid acquisition should still be configured so the intended windows fit:

| Condition | Why it matters |
| --- | --- |
| `capture_delay` must fit within half of `sync_period`. | The receive window is placed after the trigger within the active half period. |
| TX wakeup must begin before the trigger. | The TX clock and `TR_EN` need lead time before `tx_bf_sync_o`. |
| AFE wake and AFE clock lead time must begin before the trigger. | The AFE must be clocked and out of fast powerdown before receive data is expected. |
| FIFO reset must occur before FIFO start capture. | The RX FIFO should start the new shot from a clean state. |
| FIFO write-enable must cover the expected LVDS sample window. | Otherwise the FPGA will not store the requested receive samples. |
| AFE data acquisition duration must fit in the available post-trigger window. | The RTL falls back to its minimum acquisition time if the requested value is too small or too large. |
| MCU readout must happen after the FPGA indicates data is ready. | The firmware waits for the selected FPGA interrupt source before enabling readout and draining the FIFO. |

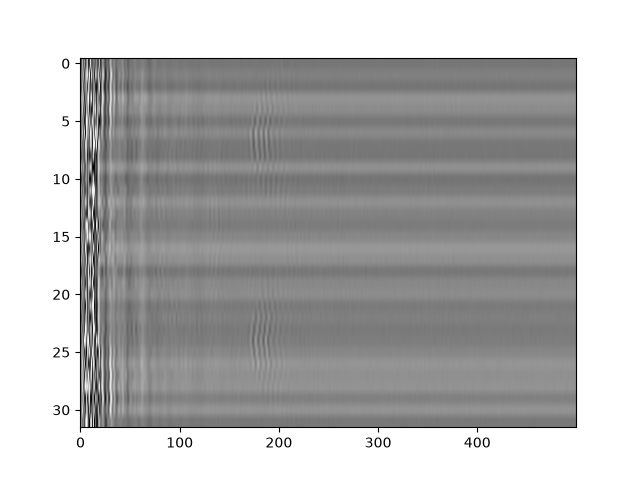
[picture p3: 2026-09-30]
software/demo/runtime/example_bitstream.png

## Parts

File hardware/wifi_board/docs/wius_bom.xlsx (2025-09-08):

Comment | Description | Designator | Footprint | LibRef | Quantity
2450AT18D0100001E | 2450AT18D0100001E 2.4 Ghz SMD Antenna Resiliant | ANT1 | FP-2450AT18D0100001E-MFG | CMP-00849-135603252-1 | 1
8.2p | Multi-Layer Ceramic Capacitor 8.2pF C0G ±0.1pF 0402 Paper T/R | C1, C4, C6 | FP-GJM155-0_05-IPC_B | CMP-2008-03885-2 | 3
12p | CAP CER 12PF 50V C0G/NP0 0402 | C2, C3 | FP-GRM155-0_05-MFG | CMP-2008-03945-2 | 2
1.3p | Multi-Layer Ceramic Capacitor 1.3pF C0G ±0.05pF 0402 Paper T/R | C5 | FP-GJM155-0_05-IPC_B | CMP-2008-03818-2 | 1
0.7p | Multi-Layer Ceramic Capacitor 0.7pF C0G ±0.05pF 0402 Paper T/R | C7 | FP-GJM155-0_05-IPC_C | CMP-2008-03909-2 | 1
18p |  | C8, C9 | CAPC1005X55X25LL05T10 | CMP-2008-04271-1 | 2
100n | Multi-Layer Ceramic Capacitor 100nF 50V X7R ±10% 0402 Paper T/R | C10, C14, C15, C17, C18, C19, C21, C23, C28, C30, C33, C34, C35, C37, C43, C50, C51 | FP-GRT155-0_05-MFG | CMP-06035-014200-1 | 17
1u | Chip Multilayer Ceramic Capacitors for General Purpose, 0402, 1.0uF, X6S, 22%, 10%, 16V | C11, C16, C22, C24, C26, C29, C31, C32, C36, C38 | FP-GRM155-0_05-MFG | CMP-06035-025126-1 | 10
10u | Cap Cer 10UF 10V X7R 0603 | C12, C13, C44, C45, C46, C48, C49, C52 | CAPC1608X100N | GMC10X7R106K10NT | 8
10n |  | C20, C41, C42 | CAPC1005X55X25LL05T10 | CMP-1034-01880-2 | 3
2.2u | Chip Multilayer Ceramic Capacitors for General Purpose, 0402, 2.2uF, X7S, 22%, 10%, 10V | C25 | FP-GRM155-0_2-IPC_C | CMP-06035-000377-1 | 1
470n | CAP CER 0.47UF 10V X5R 0402 | C47 | FP-GRM15-0_1-MFG | CMP-2000-05009-2 | 1
RED | LED GREEN/RED CLEAR CHIP SMD | D1 | FP-APTB1615SURKCGKC-F01-MFG | CMP-44529-000005-1 | 1
70m | Chip Ferrite Bead, 0402, 80Ω @ 100MHz, 0.07Ω, 25%, 1.5A | FB1, FB2 | FP-BLM15-0_05-MFG | CMP-0686-00284-4 | 2
2450BP15E0100E | Ceramic Filters Band Pass 1.5dB 50Ohm SMD 4Pin T/R | FL1 | FIL_2450BP15E0100E | 2450BP15E0100E | 1
MAX17262HEWL+ | Integrated Circuit | IC1 | BGA9C40P3X3_153X153X69 | MAX17262HEWL+ | 1
SS5-10-3.00-X-D-K-XX | 0.50mm Socket Strip Assembly | J1 | SAMTEC_SS5-10-3.00-X-D-K-XX | SS5-10-3.00-X-D-K-XX | 1
DF52-2S-0.8H(21) | Connector | J2 | DF522S08H21 | DF52-2S-0.8H_21_ | 1
2199230-5 | Conn Card Edge 67 POS 0.5mm Solder RA SMD Embossed T/R | J3 | TE_2199230-5 | 2199230-5 | 1
6.2n | Multilayer type Inductor for Automotive 6.2nH ±0.1nH 0.13Ω 700mA 0402 | L1 | FP-LQG15WH_02-IPC_C | CMP-06042-015013-1 | 1
3.4n | Multilayer type Inductor for Automotive 3.4nH ±0.1nH 0.09Ω 900mA 0402 | L2 | FP-LQG15WH_02-IPC_C | CMP-06042-011399-1 | 1
3.3n | Multilayer type RF Inductor 3.3nH ±0.3nH 0.12Ω 800mA 0402 | L3 | FP-LQG15HH_02-IPC_C | CMP-06042-003843-1 | 1
1u | FIXED IND 1.0UH 2.0A 95MOHM | L4 | FP-DFE201210U-IPC_C | CMP-06042-016601-1 | 1
2.2u | Shielded Wirewound Inductor 2.2uH 20% 1800mA 0.116Ω 0806 (2016) | L5, L6 | FP-DFE201612C-MFG | CMP-06042-009962-1 | 2
9774025151R | 9774025151R Spacer Material: Steel Mounting: SMT Series: WA-SMSI Thread D: M2.5 | MP1 | 9774025151 | CMP-03913-59774856-1 | 1
BOOT0 | Male Header, Pitch 1.27 mm, 1 x 3 Position, Height 4 mm, Tail Length 2.3 mm, -40 to 105 degC, RoHS, Bulk | P1 | SLIN-GRPB031VWVN-RC_V | CMP-2000-06372-1 | 1
BOOT1 | Male Header, Pitch 1.27 mm, 1 x 3 Position, Height 4 mm, Tail Length 2.3 mm, -40 to 105 degC, RoHS, Bulk | P2 | SLIN-GRPB031VWVN-RC_V | CMP-2000-06372-1 | 1
MOLEX_5051100892 |  | PJ1, PJ2 | MOLEX_5051100892 | MOLEX_5051100892 | 2
Resistor 0R 0402 63 mW | Chip Resistor, 0 Ohm, 0.063 W, -55 to 155 degC, 0402 (1005 Metric) | R1, R2, R4, R9, R14, R19, R27, R29, R30 | RESC1005X40X25ML05T10 | CMP-009-00004-5 | 9
100 |  | R3 | RESC1005X40X25ML05T10 | CMP-2002-07344-1 | 1
100k |  | R5, R6, R15, R16, R20, R22, R24, R26 | RESC1005X40X25NL05T10 | CMP-2002-07343-1 | 8
1k |  | R7, R8 | RESC1005X40X25LL05T10 | CMP-2002-07865-1 | 2
280 |  | R10, R11, R17, R18 | RESC1005X40X25NL05T10 | CMP-1011-00446-2 | 4
267k |  | R13 | RESC1005X40X25LL05T10 | CMP-2002-07544-1 | 1
22 |  | R31, R32, R33, R35 | RESC1005X40X25LL05T10 | CMP-2002-07520-1 | 4
B3U-1000P | SWITCH TACTILE SPST-NO 0.05A 12V | SW1, SW2 | FP-B3U-1000P-MFG | CMP-2100-03586-2 | 2
SKY13317-373LF | IC RF SWITCH SP3T 6GHZ 8MLP | U1 | FP-SKY13317-373LF-MFG | CMP-85923-000011-1 | 1
IC RF TXRX+MCU WIFI BLE 84QFN |  | U2 | SIWG917M110LGTBA | SIWG917 | 1
TPS62840YBGR | ULTRA LOW IQ BUCK CONVERTER | U4, U5 | FP-YBG0006-MFG | CMP-04918-000401-1 | 2
TPS22916CNYFPR | IC PWR SWITCH P-CHAN 1:1 4DSBGA | U6 | FP-YFP0004-IPC_C | CMP-04910-000105-1 | 1
32.768KHZ |  | Y1 | XTAL_CM8V-T1A-32.768KHZ-7PF-20PPM-TA-QC | CM8V-T1A-32.768KHZ-7PF-20PPM-TA-QC | 1
FA-20H_40.0000MF10Z-K3 |  | Y2 | XTAL_FA-20H_40.0000MF10Z-K3 | FA-20H_40.0000MF10Z-K3 | 1

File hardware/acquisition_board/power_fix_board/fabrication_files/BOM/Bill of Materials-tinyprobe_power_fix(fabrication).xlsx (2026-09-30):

Comment | Description | Designator | Footprint | LibRef | Quantity
10uF | Chip Multilayer Ceramic Capacitors for General Purpose, 0603, 10uF, X5R, 15%, 20%, 6.3V | C2, C4 | FP-GRM188-0_1-e0_2_0_55-IPC_A | CMP-2006-02792-2 | 2
100 nF | CAP CER 0.1UF 10V X5R 0402 C0402C104K8PACTU | C6 | FP-C0402-BB-MFG | CMP-2008-02046-2 | 1
1.5 MOhm | RC0402FR-071M5L | R1 | RESC1005X40X25NL05T10 | CMP-2002-07106-1 | 1
12k | ERJ-2RKF1202X | R3 | RESC1005X40X25LL05T05 | CMP-2002-00646-4 | 1
27k | ERA-2AEB273X | R4, R5 | RESC1005X40X25LL10T10 | CMP-2002-05797-1 | 2
NCP189CMTW120TAG | LDO Regulator, 0.5 A, High Accuracy (0.7%), Adjustable, Low Noise, High PSRR with Power Good | U1 | NCP189 | NCP189CMTW120TAG | 1

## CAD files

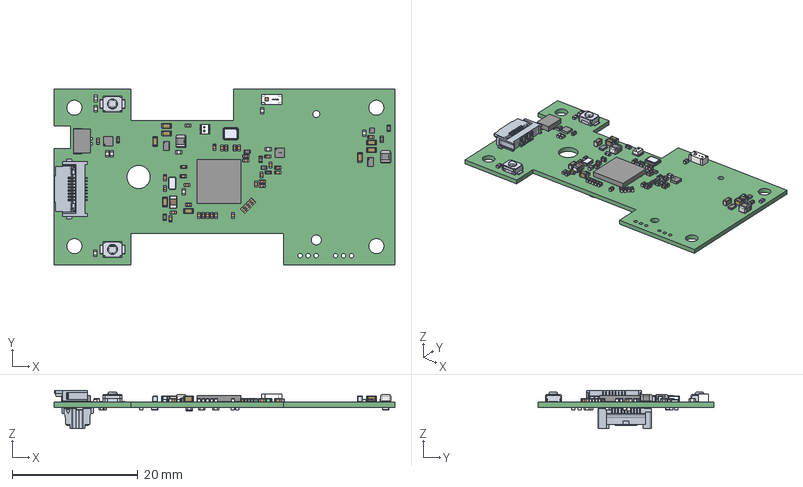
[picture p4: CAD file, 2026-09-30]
hardware/wifi_board/wius.step
54.2 x 28.0 x 6.08 mm
Extruded x 54
Mid_Body x 8
Mark x 10
side x 68
Murata x 37
BGA_body
BGA_Ball x 4
circle
Texas Instruments
Texas Logo Yury - Copy x 2
Texas Logo Yury x 2
Murata Logo 3 x 5
Terminals x 3
Center x 3
Pins x 5
Package x 2
Logo x 4
Switch_Omron_B3U-1000P_eec x 14
MainBody x 2
Polarity x 2
_SS5-10_socket
_C-229-10-3.00_
_K-DOT-.138-.250-.005_polyamide_pick_
base
top
pins
red
green
Termination

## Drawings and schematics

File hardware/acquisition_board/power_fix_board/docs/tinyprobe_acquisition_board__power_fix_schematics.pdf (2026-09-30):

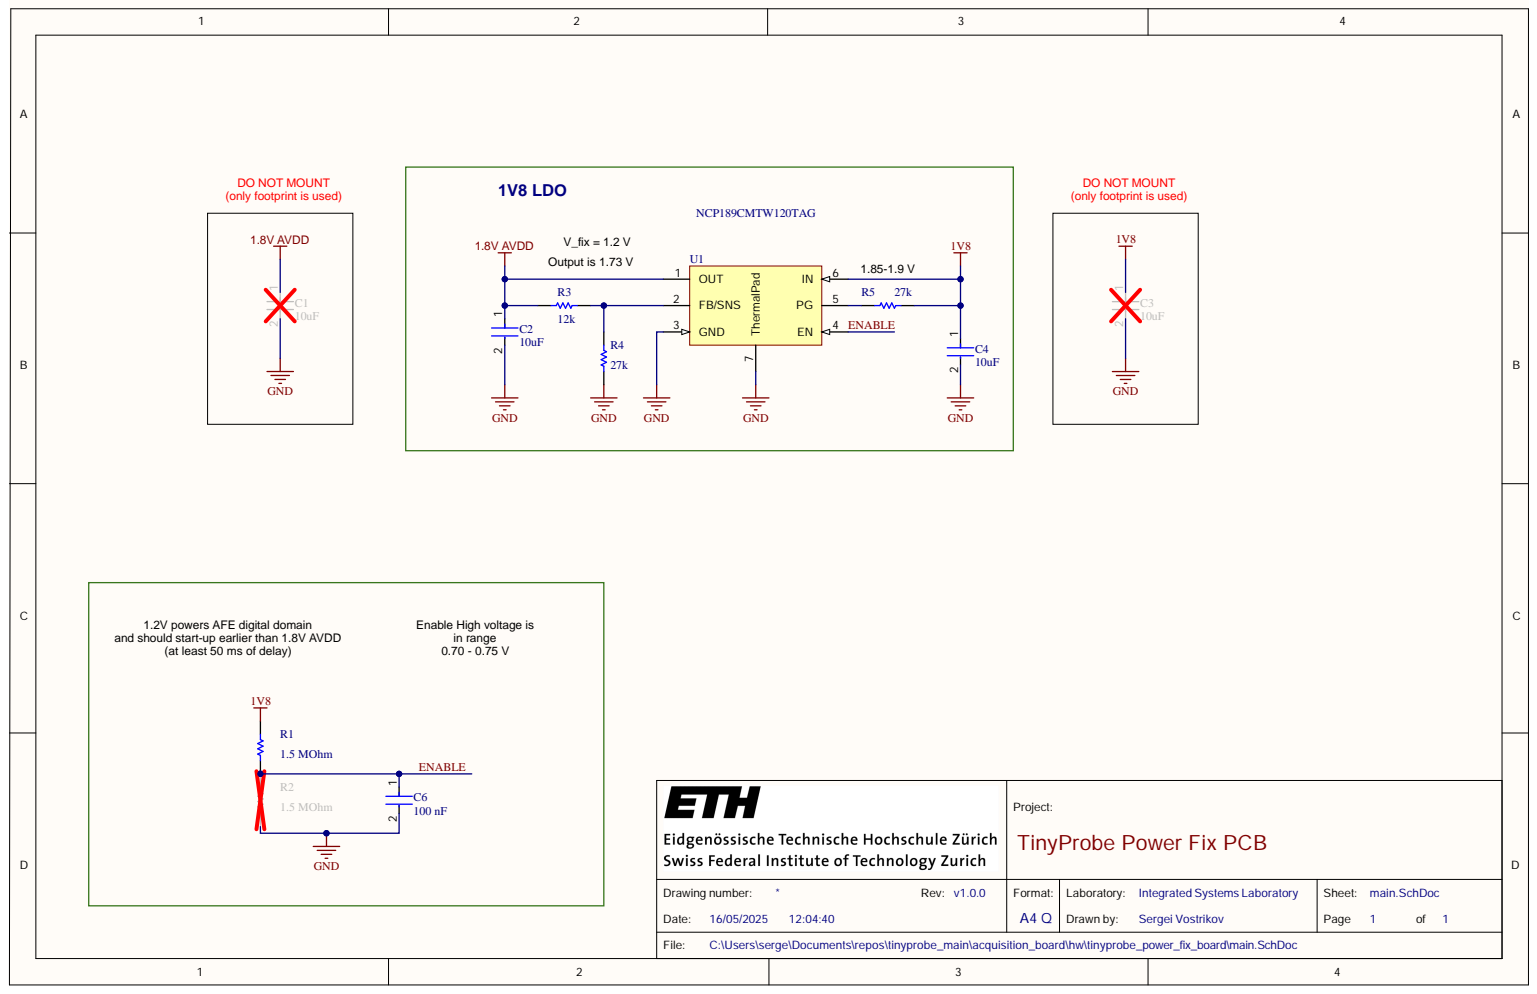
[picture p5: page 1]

DO NOT MOUNT
(only footprint is used)

1.2V powers AFE digital domain
and should start-up earlier than 1.8V AVDD

Enable High voltage is

(at least 50 ms of delay)

Project: TinyProbe Power Fix PCB

Drawing number: * Rev: v1.0.0 Date: 16/05/2025 12:04:40 | Format: A4 Q | Laboratory: Integrated Systems Laboratory Drawn by: Sergei Vostrikov | Sheet: main.SchDoc Page 1 of 1

C:\Users\serge\Documents\repos\tinyprobe_main\acquisition_board\hw\tinyprobe_power_fix_board\main.SchDoc

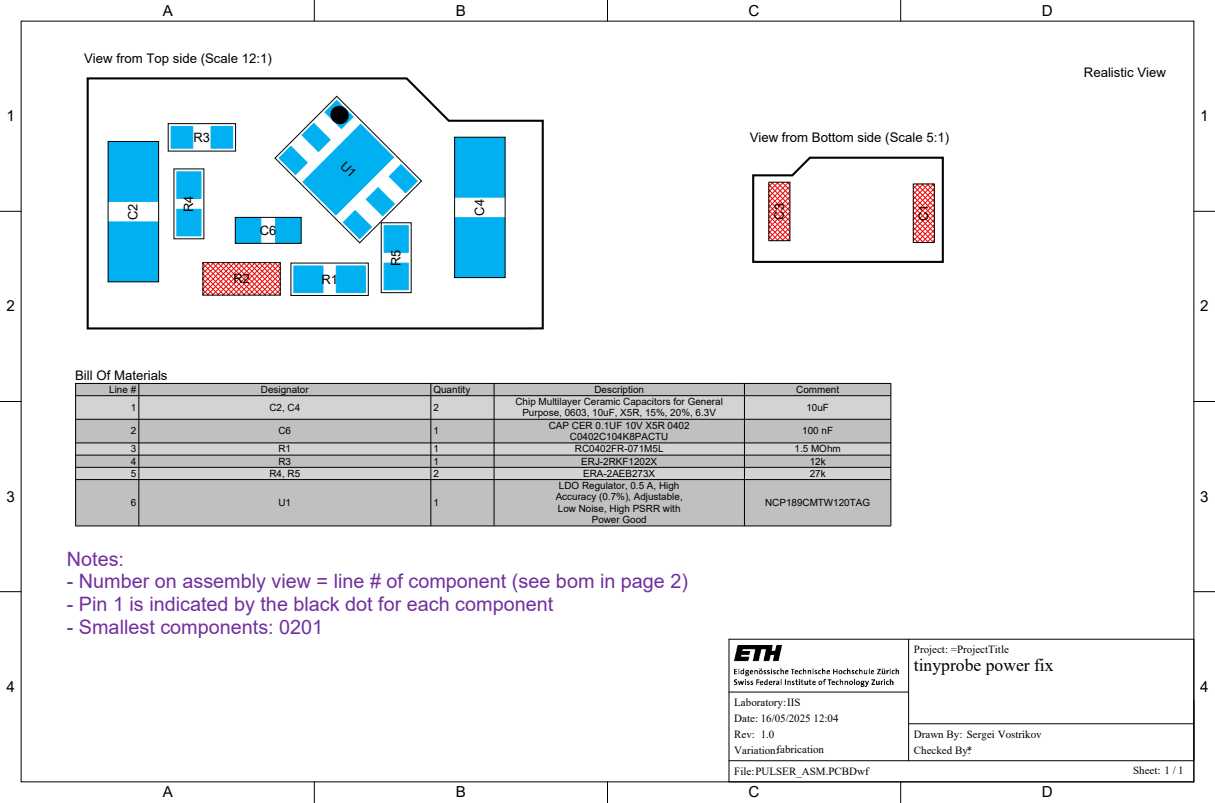
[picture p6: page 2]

View from Top side (Scale 12:1)

View from Bottom side (Scale 5:1)

Line # | Designator | Quantity | Description | Comment
1 | C2, C4 | 2 | Chip Multilayer Ceramic Capacitors for General Purpose, 0603, 10uF, X5R, 15%, 20%, 6.3V | 10uF

2 | C6 | 1 | CAP CER 0.1UF 10V X5R 0402 C0402C104K8PACTU | 100 nF

3 | R1 | 1 | RC0402FR-071M5L | 1.5 MOhm
4 | R3 | 1 | ERJ-2RKF1202X | 12k
5 | R4, R5 | 2 | ERA-2AEB273X | 27k
6 | U1 | 1 | LDO Regulator, 0.5 A, High Accuracy (0.7%), Adjustable, Low Noise, High PSRR with Power Good | NCP189CMTW120TAG

Notes:
- Number on assembly view = line # of component (see bom in page 2)
- Pin 1 is indicated by the black dot for each component
- Smallest components: 0201

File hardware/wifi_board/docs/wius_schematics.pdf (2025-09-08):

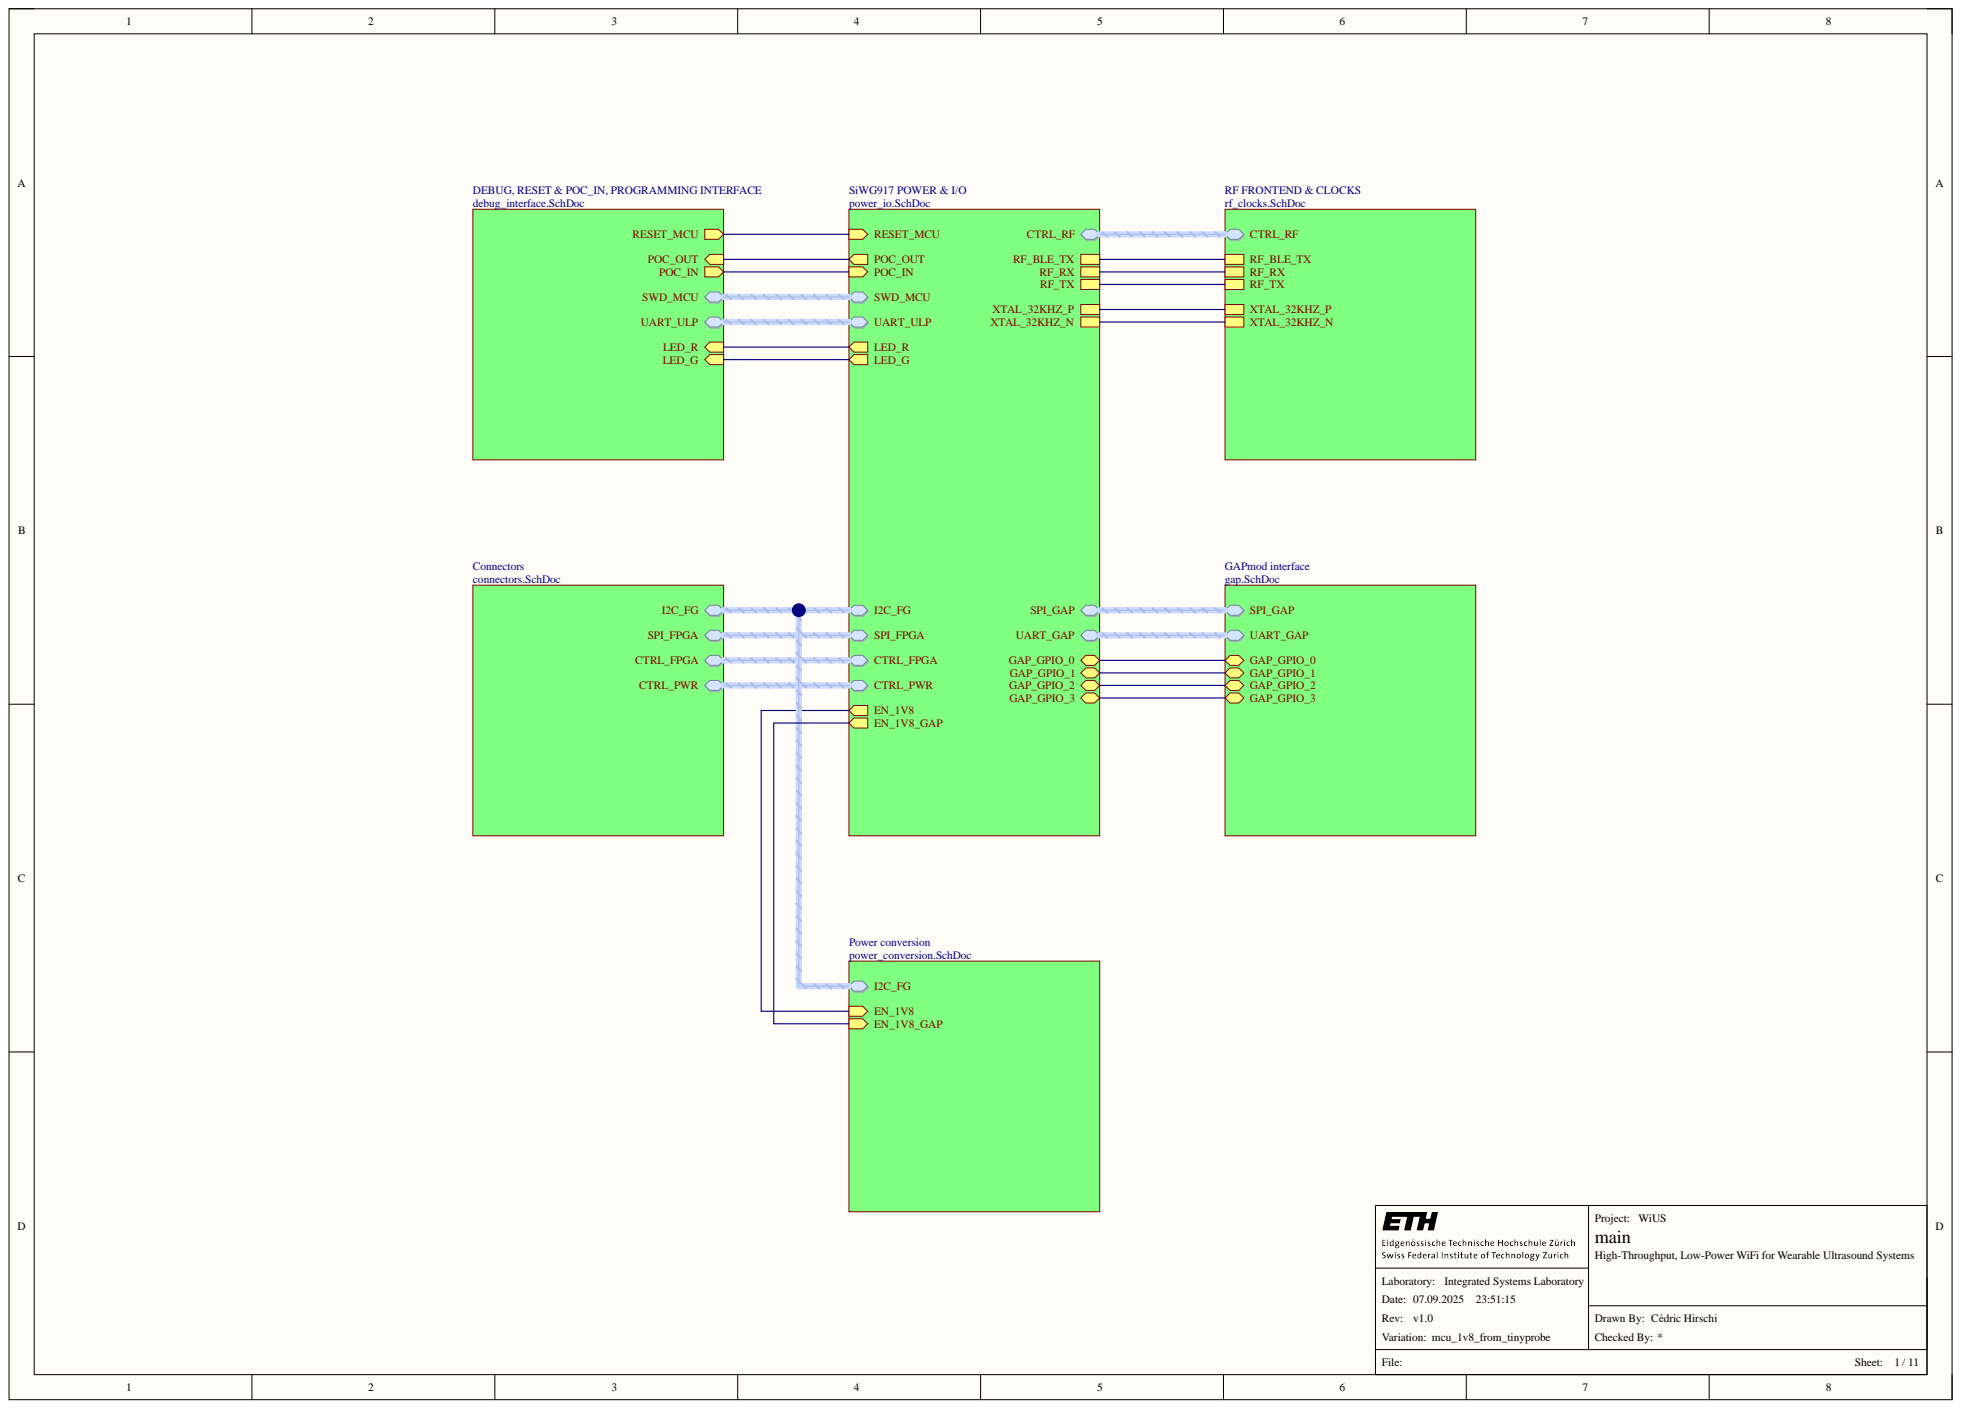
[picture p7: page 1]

DEBUG, RESET & POC_IN, PROGRAMMING INTERFACE
debug_interface.SchDoc

High-Throughput, Low-Power WiFi for Wearable Ultrasound Systems

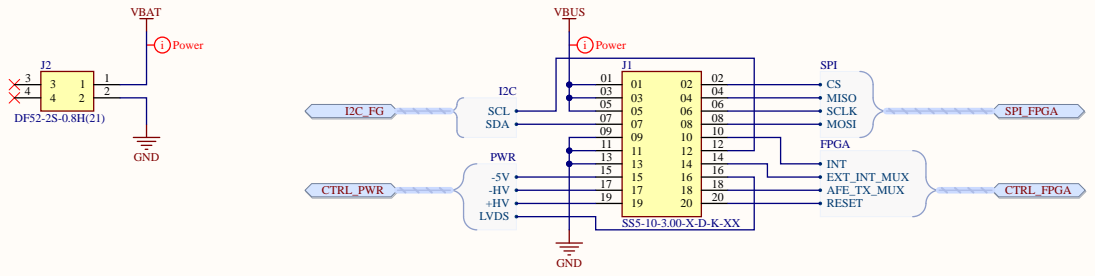
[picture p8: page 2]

High-Throughput, Low-Power WiFi for Wearable Ultrasound Systems

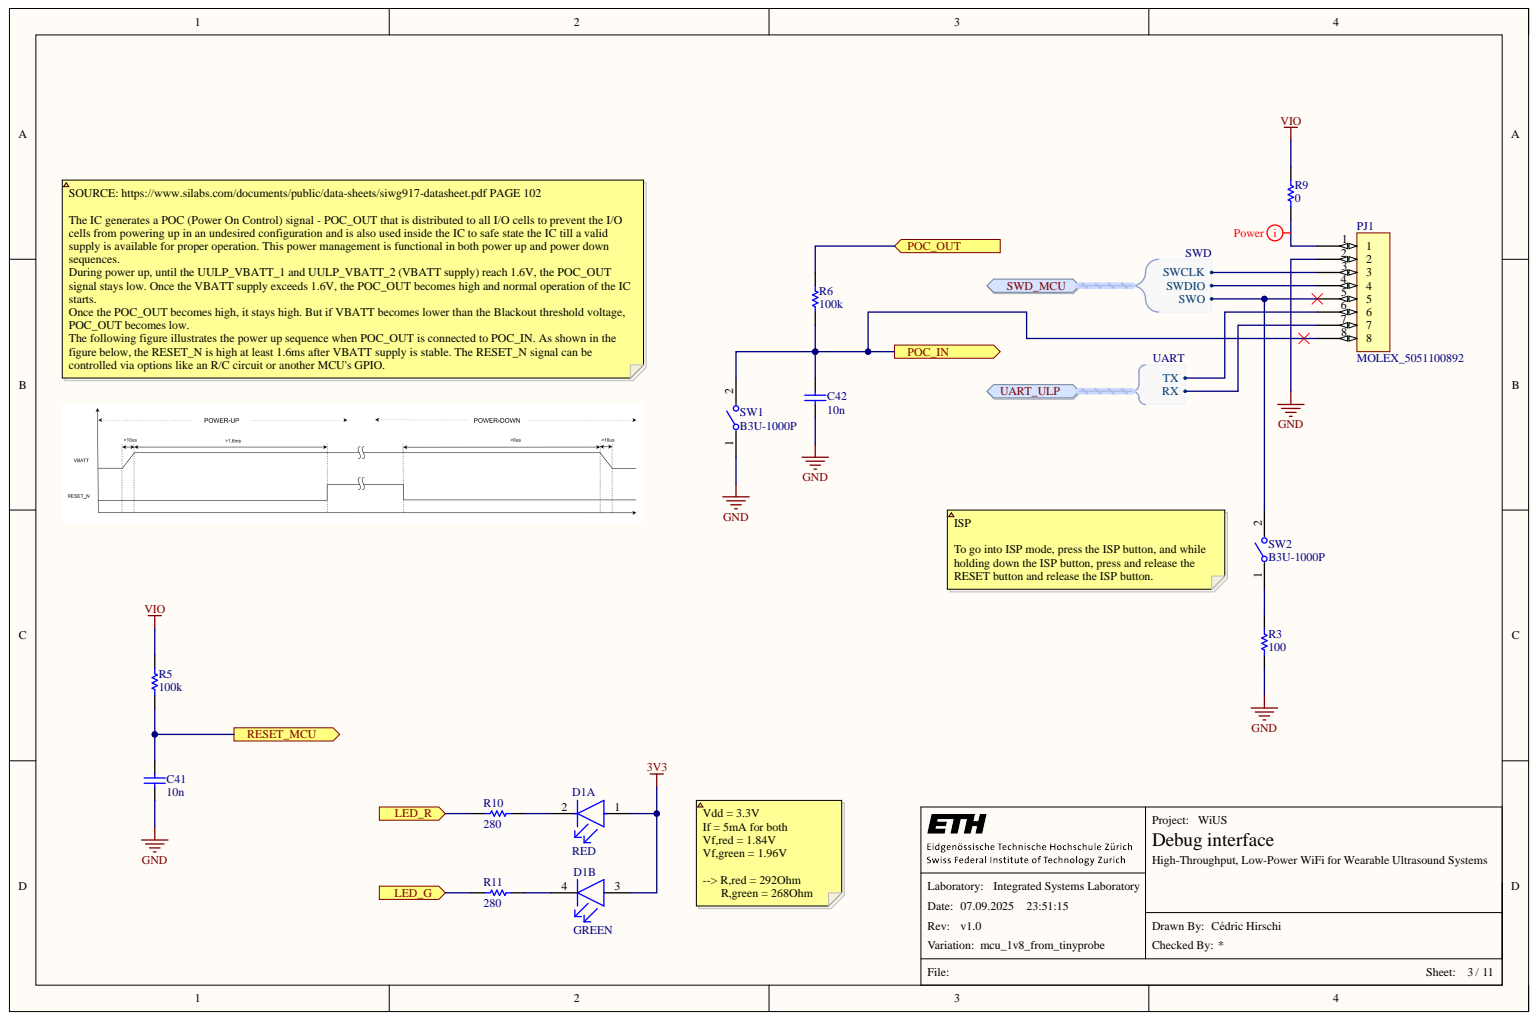
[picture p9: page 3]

SOURCE: https://www.silabs.com/documents/public/data-sheets/siwg917-datasheet.pdf PAGE 102

The IC generates a POC (Power On Control) signal - POC_OUT that is distributed to all I/O cells to prevent the I/O
cells from powering up in an undesired configuration and is also used inside the IC to safe state the IC till a valid
supply is available for proper operation. This power management is functional in both power up and power down
sequences.
During power up, until the UULP_VBATT_1 and UULP_VBATT_2 (VBATT supply) reach 1.6V, the POC_OUT
signal stays low. Once the VBATT supply exceeds 1.6V, the POC_OUT becomes high and normal operation of the IC
starts.
Once the POC_OUT becomes high, it stays high. But if VBATT becomes lower than the Blackout threshold voltage,
POC_OUT becomes low.
The following figure illustrates the power up sequence when POC_OUT is connected to POC_IN. As shown in the
figure below, the RESET_N is high at least 1.6ms after VBATT supply is stable. The RESET_N signal can be
controlled via options like an R/C circuit or another MCU's GPIO.

To go into ISP mode, press the ISP button, and while
holding down the ISP button, press and release the
RESET button and release the ISP button.

High-Throughput, Low-Power WiFi for Wearable Ultrasound Systems

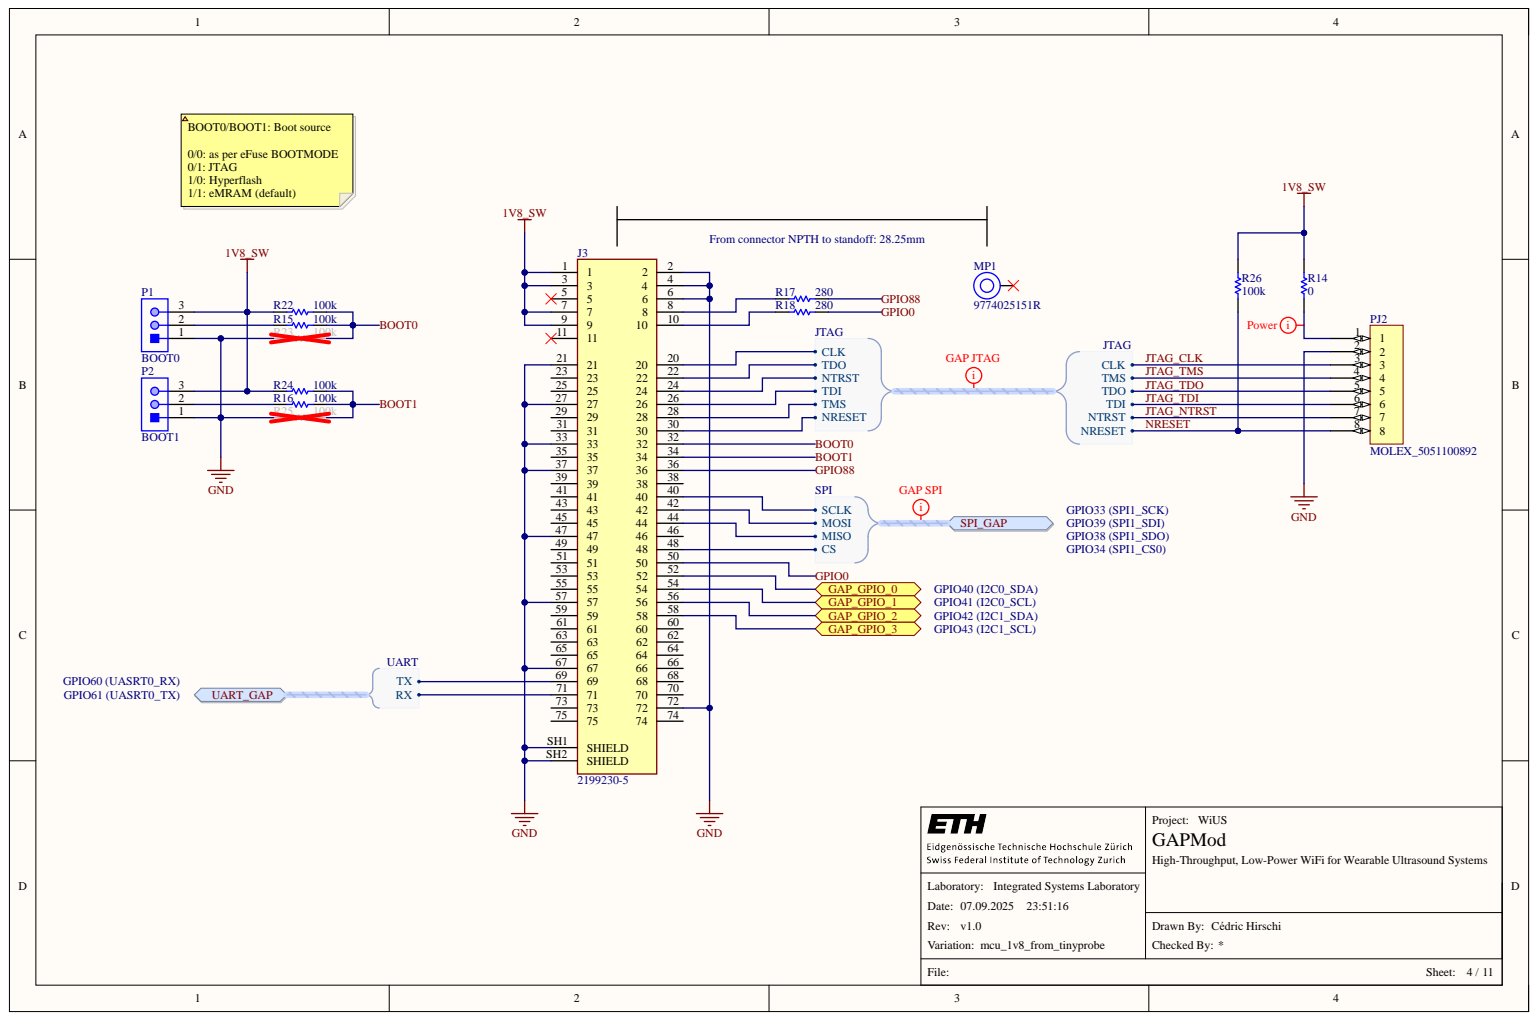
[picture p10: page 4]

0/0: as per eFuse BOOTMODE
0/1: JTAG
1/0: Hyperflash
1/1: eMRAM (default)

From connector NPTH to standoff: 28.25mm

5 | 6 8

High-Throughput, Low-Power WiFi for Wearable Ultrasound Systems

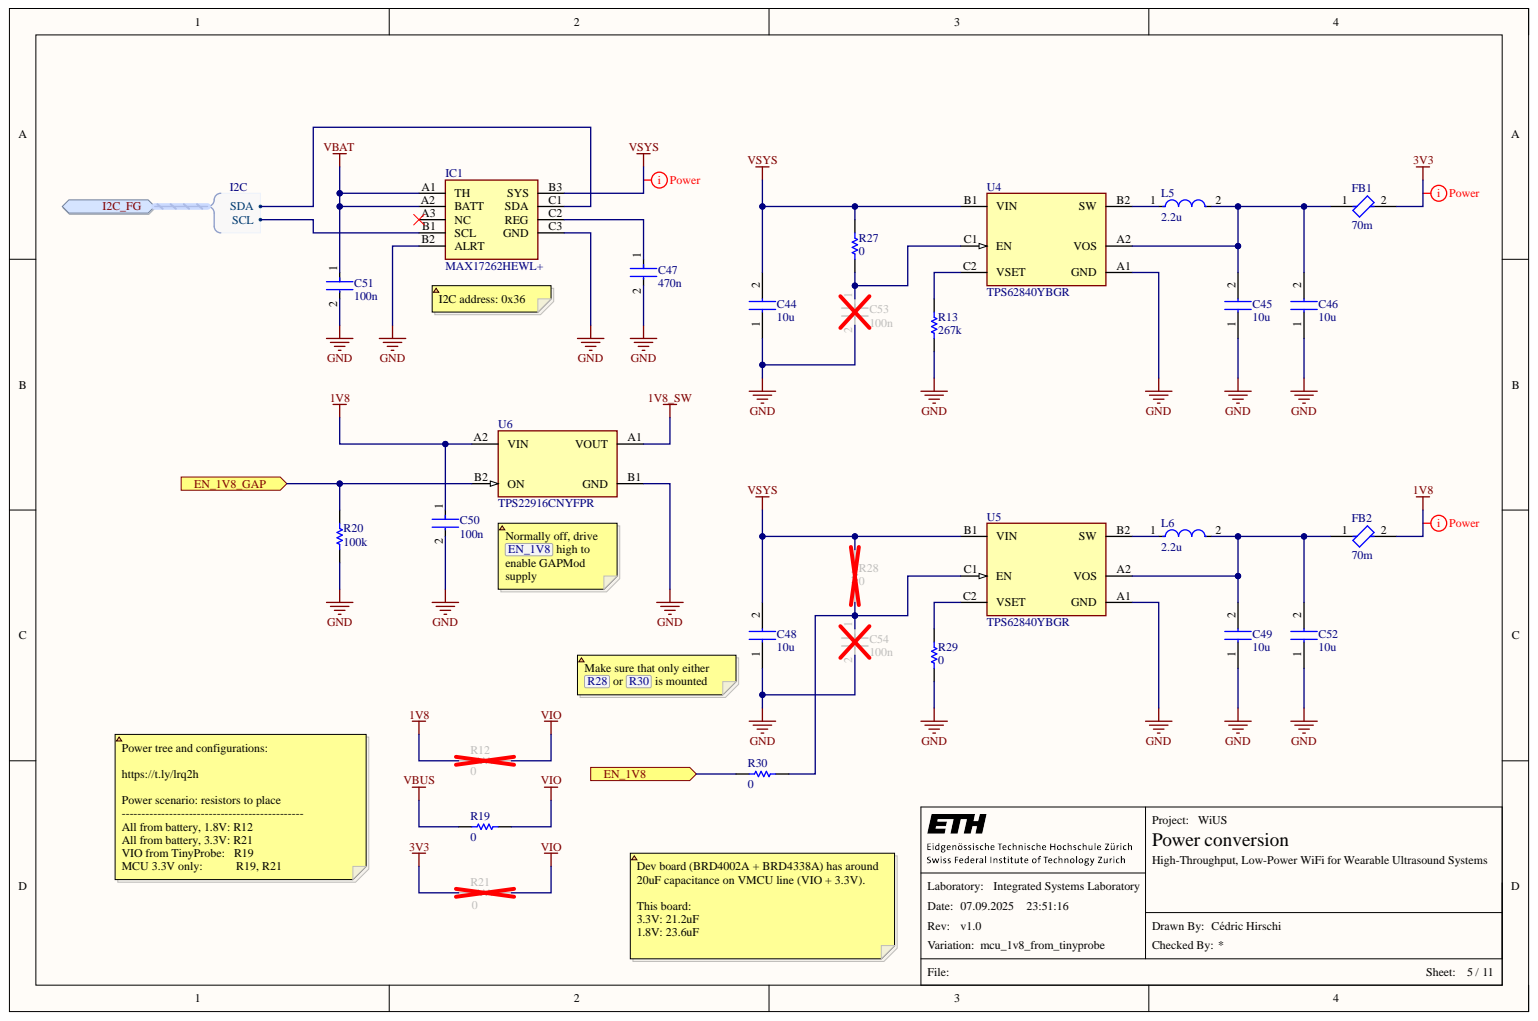
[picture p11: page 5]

SCL B1

Make sure that only either
R28 or R30 is mounted

Power tree and configurations:

Power scenario: resistors to place
All from battery, 1.8V: R12
All from battery, 3.3V: R21
VIO from TinyProbe: R19

Dev board (BRD4002A + BRD4338A) has around
20uF capacitance on VMCU line (VIO + 3.3V).

High-Throughput, Low-Power WiFi for Wearable Ultrasound Systems

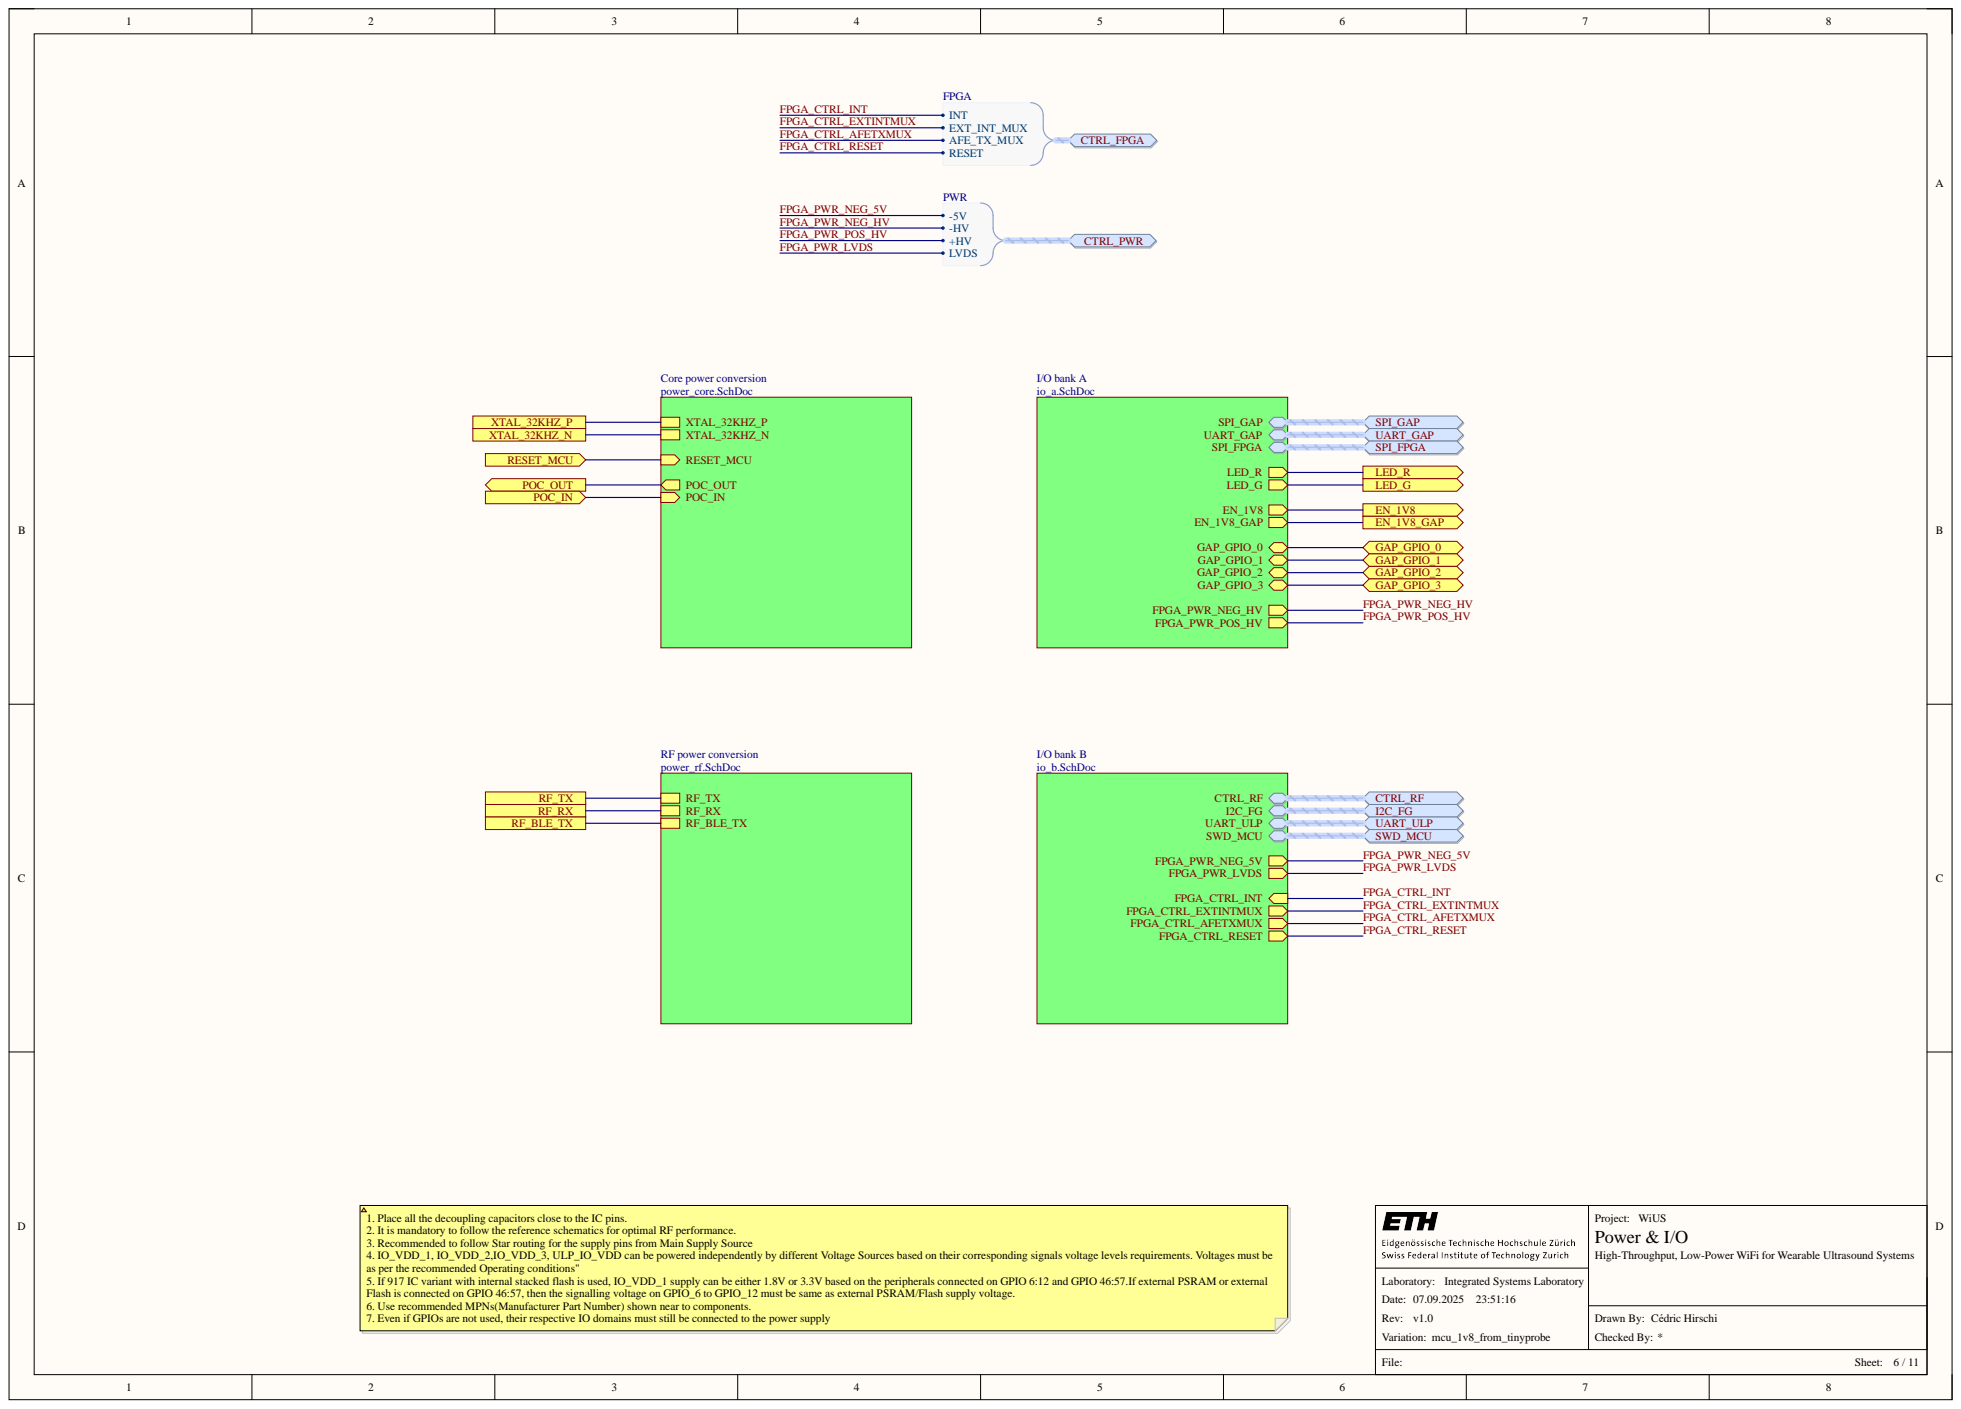
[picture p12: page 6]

1. Place all the decoupling capacitors close to the IC pins.
2. It is mandatory to follow the reference schematics for optimal RF performance.
3. Recommended to follow Star routing for the supply pins from Main Supply Source
4. IO_VDD_1, IO_VDD_2,IO_VDD_3, ULP_IO_VDD can be powered independently by different Voltage Sources based on their corresponding signals voltage levels requirements. Voltages must be
as per the recommended Operating conditions"
5. If 917 IC variant with internal stacked flash is used, IO_VDD_1 supply can be either 1.8V or 3.3V based on the peripherals connected on GPIO 6:12 and GPIO 46:57.If external PSRAM or external
Flash is connected on GPIO 46:57, then the signalling voltage on GPIO_6 to GPIO_12 must be same as external PSRAM/Flash supply voltage.
6. Use recommended MPNs(Manufacturer Part Number) shown near to components.
7. Even if GPIOs are not used, their respective IO domains must still be connected to the power supply

High-Throughput, Low-Power WiFi for Wearable Ultrasound Systems

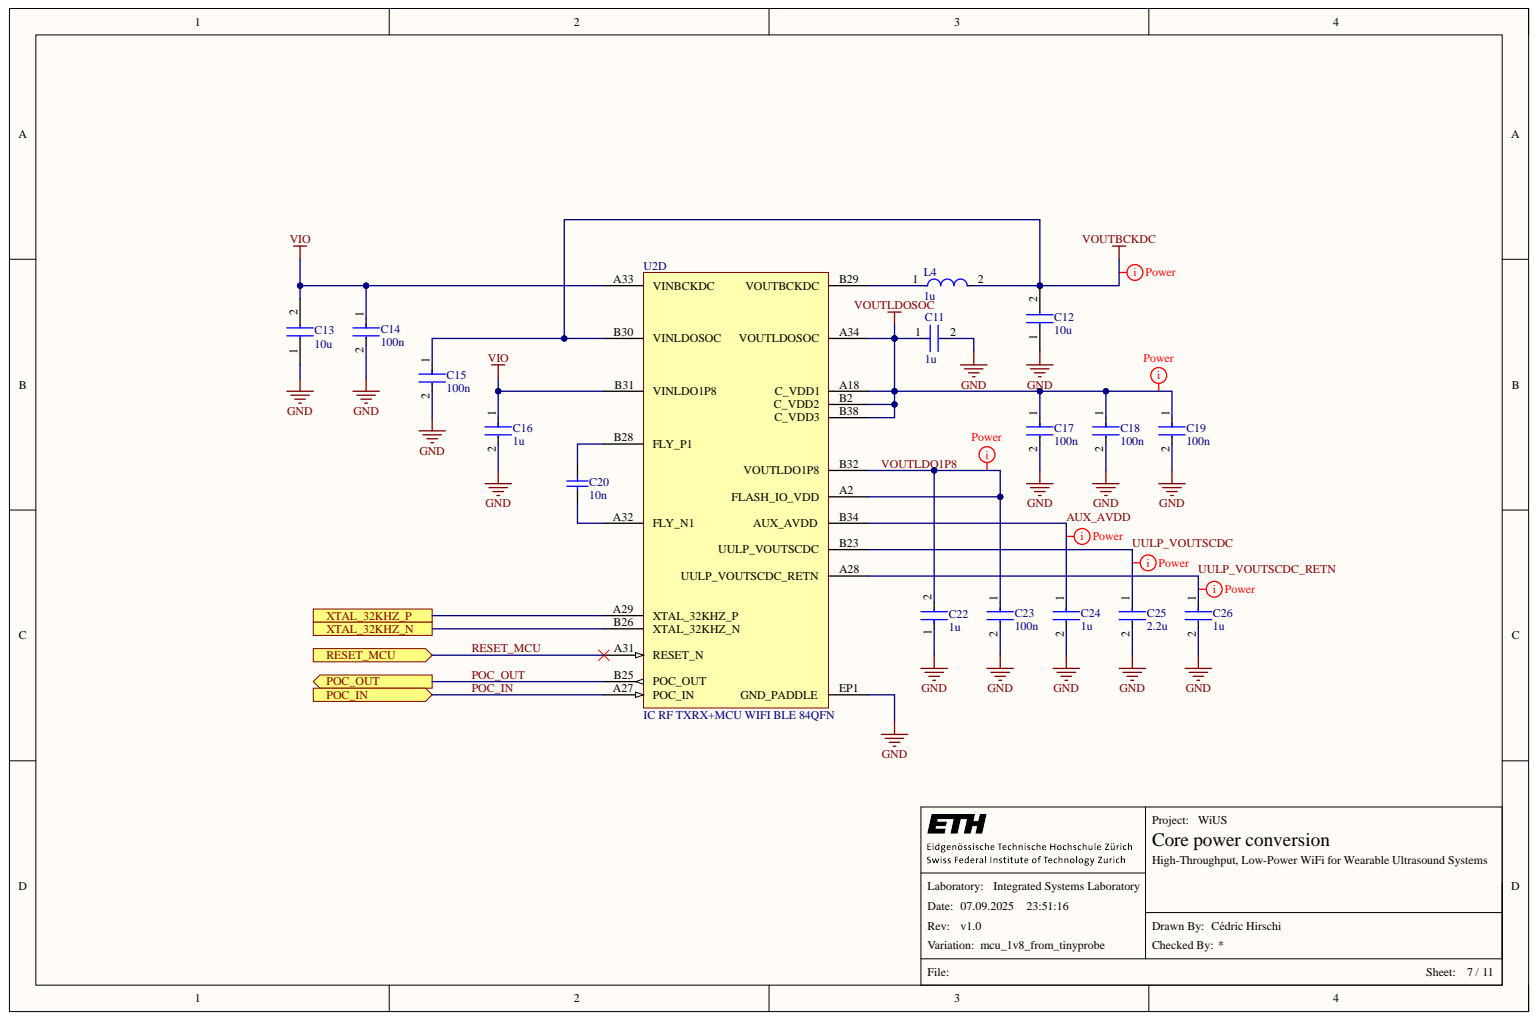
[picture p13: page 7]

VINLDOSOC B30

FLY_P1 B28

IC RF TXRX+MCU WIFI BLE 84QFN

High-Throughput, Low-Power WiFi for Wearable Ultrasound Systems

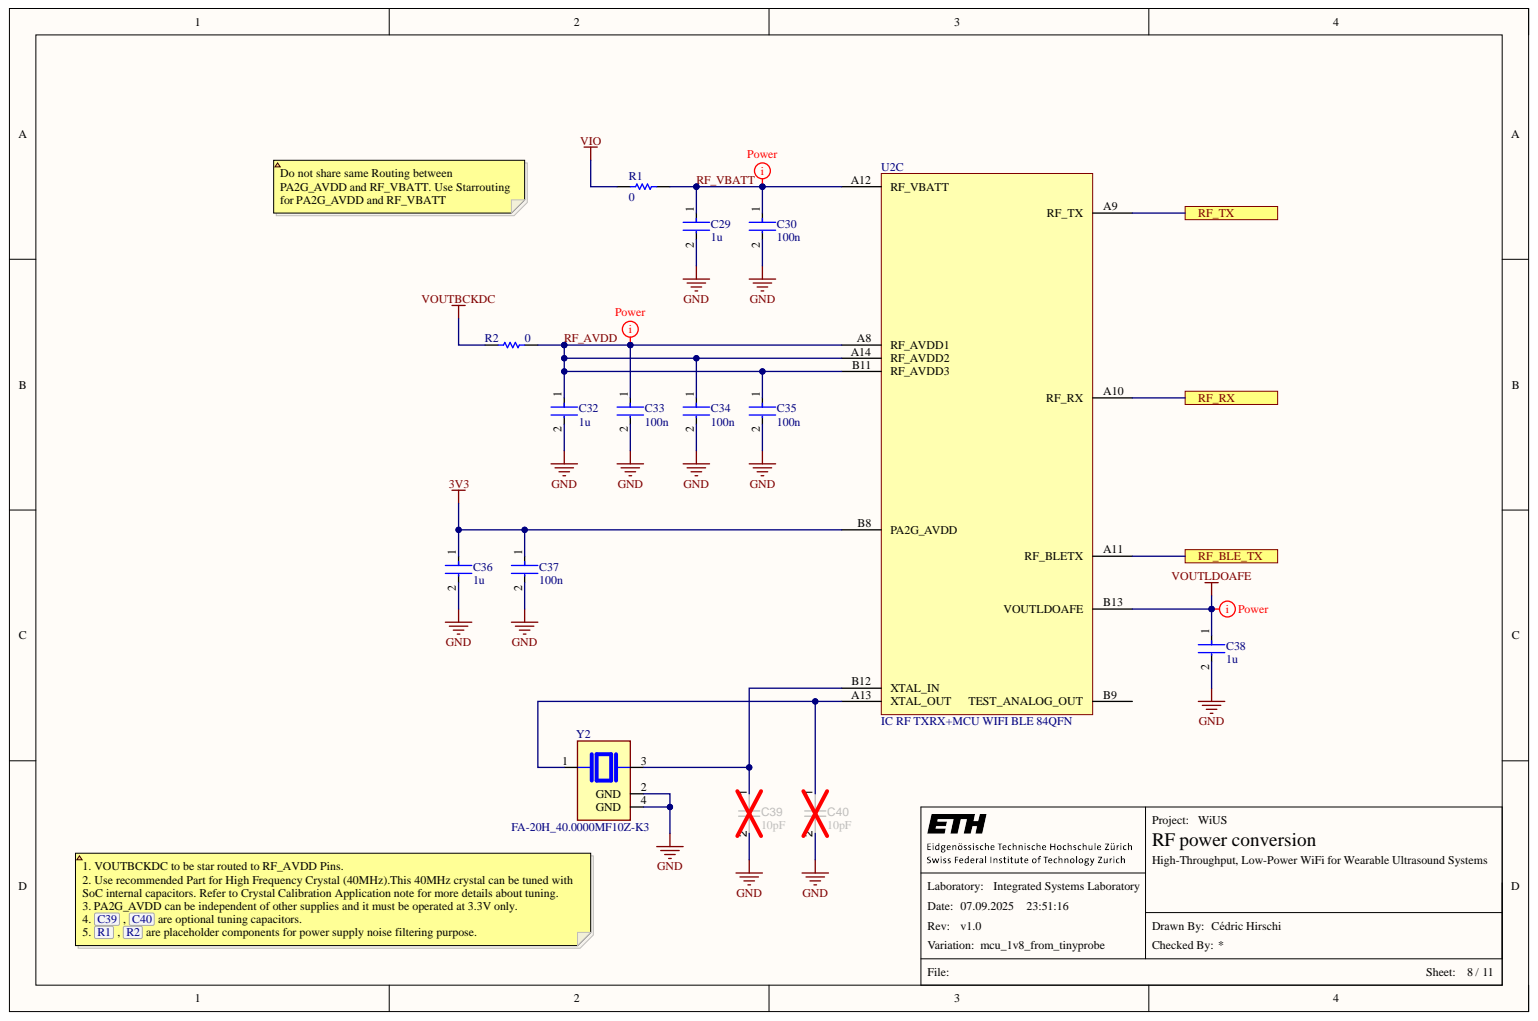
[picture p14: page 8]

Do not share same Routing between
PA2G_AVDD and RF_VBATT. Use Starrouting
for PA2G_AVDD and RF_VBATT

RF_AVDD3 B11

XTAL_IN B12

IC RF TXRX+MCU WIFI BLE 84QFN

1. VOUTBCKDC to be star routed to RF_AVDD Pins.
2. Use recommended Part for High Frequency Crystal (40MHz).This 40MHz crystal can be tuned with
SoC internal capacitors. Refer to Crystal Calibration Application note for more details about tuning.
3. PA2G_AVDD can be independent of other supplies and it must be operated at 3.3V only.
4. C39 , C40 are optional tuning capacitors.
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

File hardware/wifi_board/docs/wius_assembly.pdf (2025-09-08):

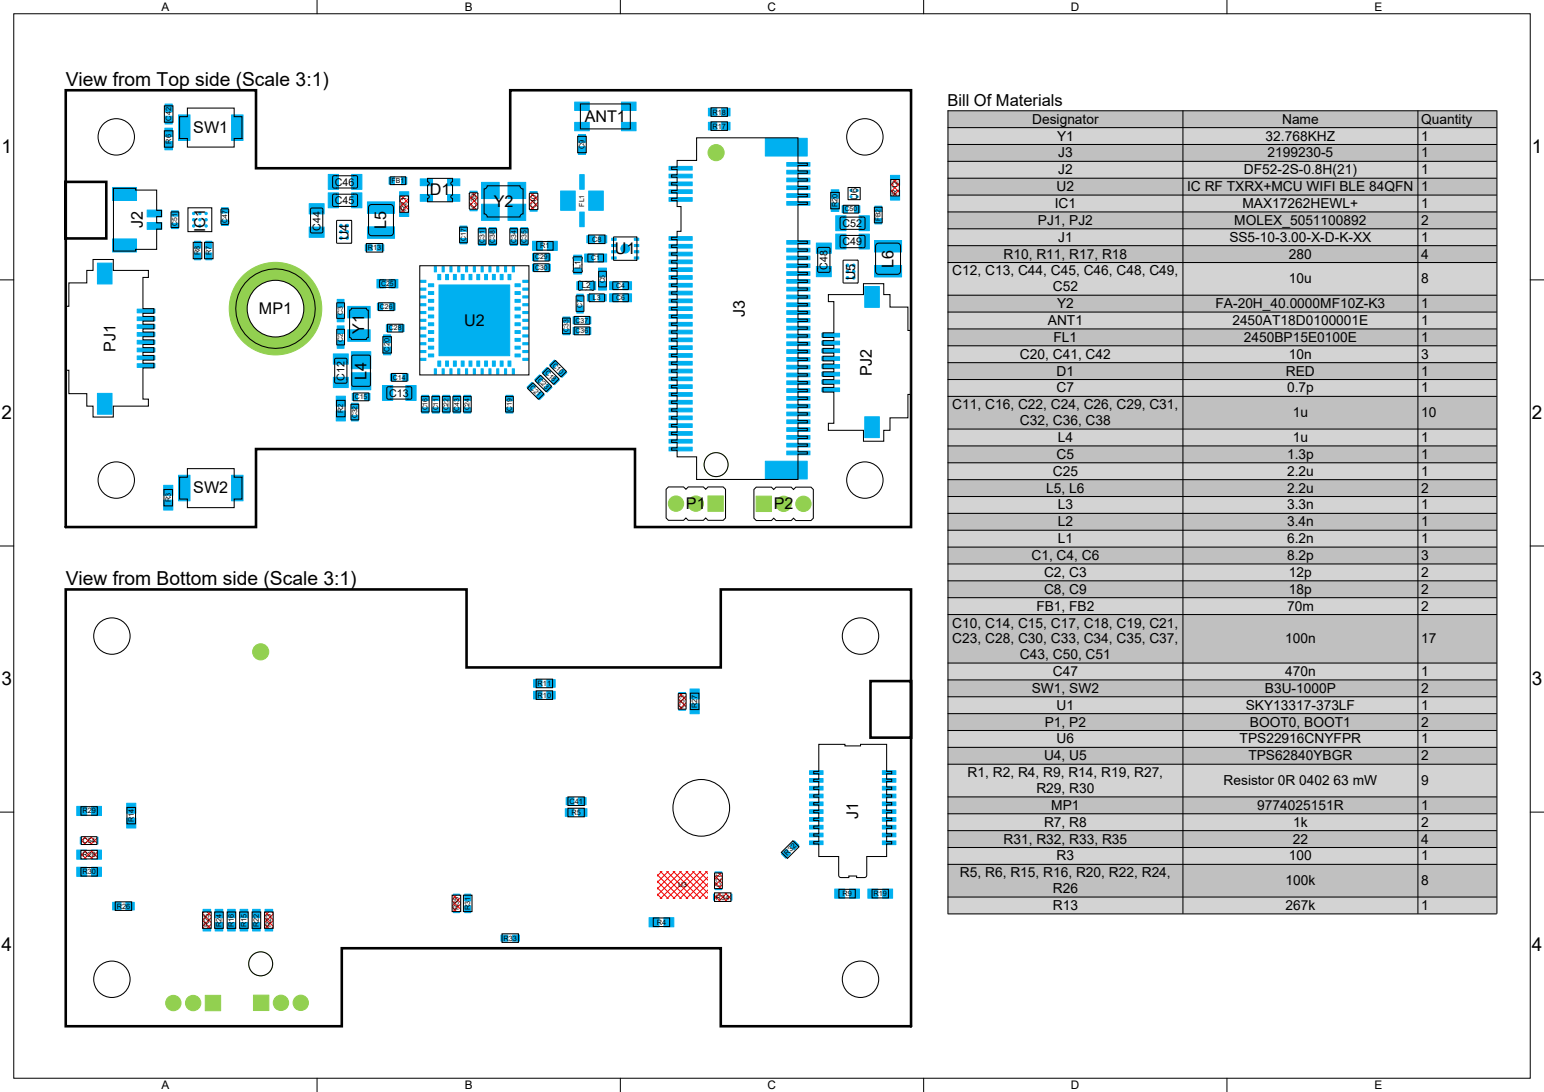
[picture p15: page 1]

View from Top side (Scale 3:1)

Y1 | 32.768KHZ | 1
J3 | 2199230-5 | 1
J2 | DF52-2S-0.8H(21) | 1
U2 | IC RF TXRX+MCU WIFI BLE 84QFN | 1
IC1 | MAX17262HEWL+ | 1
PJ1, PJ2 | MOLEX_5051100892 | 2
J1 | SS5-10-3.00-X-D-K-XX | 1

Y2 | FA-20H_40.0000MF10Z-K3 | 1
ANT1 | 2450AT18D0100001E | 1
FL1 | 2450BP15E0100E | 1
C20, C41, C42 | 10n | 3
D1 | RED | 1
C7 | 0.7p | 1

L4 | 1u | 1
C5 | 1.3p | 1
C25 | 2.2u | 1
L5, L6 | 2.2u | 2
L3 | 3.3n | 1
L2 | 3.4n | 1
L1 | 6.2n | 1
C1, C4, C6 | 8.2p | 3
C2, C3 | 12p | 2
C8, C9 | 18p | 2
FB1, FB2 | 70m | 2

View from Bottom side (Scale 3:1)

U1 | SKY13317-373LF | 1
P1, P2 | BOOT0, BOOT1 | 2
U6 | TPS22916CNYFPR | 1
U4, U5 | TPS62840YBGR | 2

R1, R2, R4, R9, R14, R19, R27, R29, R30 | Resistor 0R 0402 63 mW | 9

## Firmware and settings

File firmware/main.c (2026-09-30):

/**
 * @file main.c
 *
 * @brief User main source file
 *
 * @date 03.09.2026
 * @copyright Copyright (C) 2026 ETH Zurich. All rights reserved.
 *
 * @author Cédric Hirschi, ETH Zürich
 *
 * @ingroup common
 *
 * @parblock
 * Licensed under the Apache License, Version 2.0 (the "License");
 * you may not use this file except in compliance with the License.
 * You may obtain a copy of the License at
 *
 *     http://www.apache.org/licenses/LICENSE-2.0
 *
 * Unless required by applicable law or agreed to in writing, software
 * distributed under the License is distributed on an "AS IS" BASIS,
 * WITHOUT WARRANTIES OR CONDITIONS OF ANY KIND, either express or implied.
 * See the License for the specific language governing permissions and
 * limitations under the License.
 * @endparblock
 *
 */

#include "sl_main_init.h"
#include "sl_main_kernel.h"

#include "SEGGER_RTT.h"

#include "user/user.h"

/**
 * @brief Main function
 *
 * @return int
 *
 */
int main(void)
{
  // Initialize Silicon Labs device, system, service(s) and protocol stack(s).
  sl_main_second_stage_init();

  user_init();

  return 0;
}

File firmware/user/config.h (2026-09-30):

/**
 * @file config.h
 *
 * @brief Configuration header file
 *
 * @date 03.09.2026
 * @copyright Copyright (C) 2026 ETH Zurich. All rights reserved.
 *
 * @author Cédric Hirschi, ETH Zürich
 *
 * @ingroup common
 *
 * @parblock
 * Licensed under the Apache License, Version 2.0 (the "License");
 * you may not use this file except in compliance with the License.
 * You may obtain a copy of the License at
 *
 *     http://www.apache.org/licenses/LICENSE-2.0
 *
 * Unless required by applicable law or agreed to in writing, software
 * distributed under the License is distributed on an "AS IS" BASIS,
 * WITHOUT WARRANTIES OR CONDITIONS OF ANY KIND, either express or implied.
 * See the License for the specific language governing permissions and
 * limitations under the License.
 * @endparblock
 *
 */

#pragma once

#include "env.h"

/**
 * @defgroup config_common Common firmware configurations
 * This module documents the common firmware configurations.
 * @ingroup common
 * @{
 */

/**
 * @name Board configurations
 * @{
 */
//!< Board type for WiUS firmware. Can be one of 0: "DK2605A", 1: "EK2708A", 2: "PK6031A", 3: "WIUS1".
#define WIUS_BOARD 3
/** @}
 */

/**
 * @name Logging configurations
 * @{
 */
//!< Maximum number of log callbacks that can be registered
#define LOG_MAX_CALLBACKS 1
//!< Size of the log buffer in bytes
#define LOG_BUFFER_SIZE 128
//!< Remove lifetime of log library (no deinitialization, no callback unregistration)
#define LOG_ONCE
#define LOG_NO_COLOR
/** @}
 */

/** @} End of config_common group */

/**
 * @defgroup config_wius WiUS firmware configurations
 * This module documents the firmware configurations specific to WiUS.
 * @ingroup wius
 * @{
 */

/** @name WiUS SPI configurations
 * @{
 */
//! SPI clock frequency in Hz
#define WIUS_SPI_FREQ 32000000
//! SPI timeout for transmission in ticks
#define WIUS_SPI_RX_TIMEOUT 100
//! Maximum transfer size that waits by polling an interrupt-updated flag
#define WIUS_SPI_SHORT_XFER_MAX 16
//! CS pin number for instance 0 (set to 0 if unused)
#define WIUS_SPI_EXT_CS0 53
//! CS pin number for instance 1 (set to 0 if unused)
#define WIUS_SPI_EXT_CS1 0
/** @}
 */

/** @name WiUS WiFi configurations
 * @{
 */
#ifndef WIUS_WIFI_SSID
#error "Please define WIUS_WIFI_SSID in env.h"
#endif
#ifndef WIUS_WIFI_PASS
#error "Please define WIUS_WIFI_PASS in env.h"
#endif
//! Device name for WiFi
#define WIUS_WIFI_DEVICE_NAME "WiUS"
/** @}
 */

/** @} End of config_wius group */

/** @defgroup config_tinyprobe TinyProbe firmware configurations
 *  This module documents the firmware configurations specific to TinyProbe.
 *  @ingroup tinyprobe
 *  @{
 */

/** @name TinyProbe general configurations
 * @{
 */
//! Enable test mode (1=enabled, 0=disabled). Used for testing acquisition code without actual TinyProbe hardware.
#define TP_TEST_MODE 0
//! ID of the probe (used for Ping responses)
#define TP_PROBE_ID 1
//! Size of the WiFi RX buffer
#define TP_WIFI_RX_BUFFER_SIZE 1472
//! Size of one UDP packet (no header)
#define TP_UDP_PACKET_SIZE 1000
//! Number of packets to acquire per SPI before sending
#define TP_UDP_PACKET_AMT 1
//! Port on which UDP transfers happen
#define TP_UDP_PORT 50007
//! Port on which TCP transfers happen
#define TP_TCP_PORT 50008
//! FPGA Interrupt UULP gpio number
#define TP_GPIO_INT 2
//! FPGA Reset ULP gpio number
#define TP_GPIO_RESET 10
//! Stack size for main thread
#define TP_THREAD_STACK_MAIN 4500
//! Stack size for WiFi thread
#define TP_THREAD_STACK_WIFI 1500
/** @}
 */

/** @name TinyProbe AFE control configurations
 * @{
 */
//! Delay after SPI transfers in ns
#define TP_AFE_SPI_DELAY_NS 0
/** @}
 */

/** @name TinyProbe buffering configurations
 * @{
 */
//! Number of buffers available for data acquisition
#define TP_BUFFER_NUM 10
//! FIFO read size in bytes
#define TP_FIFO_READ_SIZE (TP_UDP_PACKET_SIZE * TP_UDP_PACKET_AMT)
//! Size of one buffer in bytes (FIFO read size + 2 bytes for packet index)
#define TP_BUFFER_SIZE (TP_FIFO_READ_SIZE + 2)
/** @}
 */

/** @name TinyProbe methods configurations
 * @{
 */
//! Response buffer size for JSON-RPC methods in bytes
#define TP_RESPONSE_BUFFER_SIZE 1024
//! Enable per-method DWT timing logs
#define TP_METHOD_TIMING 0
/** @}
 */

/** @name TinyProbe FPGA control configurations
 * @{
 */
//! Delay after SPI transfers in ns
#define TP_FPGA_SPI_DELAY_NS 50
/** @}
 */

/** @name TinyProbe MUX control configurations
 * @{
 */
//! EXT INT MUX UULP gpio number
#define TP_MUX_GPIO_EXTINT 3
//! AFE TX MUX ULP gpio number
#define TP_MUX_GPIO_AFETX 1
/** @}
 */

/** @name TinyProbe power control configurations
 * @{
 */
//! -5V ULP gpio number
#define TP_POWER_GPIO_NEG_5V 2
//! -HV gpio number
#define TP_POWER_GPIO_NEG_HV 52
//! +HV gpio number
#define TP_POWER_GPIO_POS_HV 56
//! LVDS power switch ULP gpio number
#define TP_POWER_GPIO_LVDS_PWR_SW 8
/** @}
 */

/** @} End of config_tinyprobe group */
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

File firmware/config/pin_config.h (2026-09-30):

/**
 * @file pin_config.h
 *
 * @brief TinyProbe/WiUS board pin assignments
 *
 * @date 22.09.2026
 * @copyright Copyright (C) 2026 ETH Zurich. All rights reserved.
 *
 * @ingroup wius
 *
 * @details
 *
 * Project-owned TinyProbe/WiUS board pin assignments. Maintain this file in
 * source control; it is not generated SDK configuration.
 *
 * The SDK's RTE_Device_917.h consumes these macro names. HP is the SDK's
 * high-performance GPIO port; LOC values select the corresponding pin routes.
 *
 * @parblock
 * Licensed under the Apache License, Version 2.0 (the "License");
 * you may not use this file except in compliance with the License.
 * You may obtain a copy of the License at
 *
 *     http://www.apache.org/licenses/LICENSE-2.0
 *
 * Unless required by applicable law or agreed to in writing, software
 * distributed under the License is distributed on an "AS IS" BASIS,
 * WITHOUT WARRANTIES OR CONDITIONS OF ANY KIND, either express or implied.
 * See the License for the specific language governing permissions and
 * limitations under the License.
 * @endparblock
 *
 */

#ifndef PIN_CONFIG_H
#define PIN_CONFIG_H

/* SSI: MOSI GPIO 26, MISO GPIO 27, clock GPIO 25, chip select GPIO 28. */
#ifndef SSI_MASTER_MOSI_DATA0_PORT
#define SSI_MASTER_MOSI_DATA0_PORT HP
#endif
#ifndef SSI_MASTER_MOSI_DATA0_PIN
#define SSI_MASTER_MOSI_DATA0_PIN 26
#endif
#ifndef SSI_MASTER_DATA0_LOC
#define SSI_MASTER_DATA0_LOC 1
#endif

#ifndef SSI_MASTER_MISO_DATA1_PORT
#define SSI_MASTER_MISO_DATA1_PORT HP
#endif
#ifndef SSI_MASTER_MISO_DATA1_PIN
#define SSI_MASTER_MISO_DATA1_PIN 27
#endif
#ifndef SSI_MASTER_DATA1_LOC
#define SSI_MASTER_DATA1_LOC 4
#endif

#ifndef SSI_MASTER_SCK__PORT
#define SSI_MASTER_SCK__PORT HP
#endif
#ifndef SSI_MASTER_SCK__PIN
#define SSI_MASTER_SCK__PIN 25
#endif
#ifndef SSI_MASTER_SCK_LOC
#define SSI_MASTER_SCK_LOC 7
#endif

#ifndef SSI_MASTER_CS0__PORT
#define SSI_MASTER_CS0__PORT HP
#endif
#ifndef SSI_MASTER_CS0__PIN
#define SSI_MASTER_CS0__PIN 28
#endif
#ifndef SSI_MASTER_CS0_LOC
#define SSI_MASTER_CS0_LOC 10
#endif


/* GSPI: MOSI GPIO 27, MISO GPIO 26, clock GPIO 25, chip select GPIO 28. */
#ifndef GSPI_MASTER_MOSI__PORT
#define GSPI_MASTER_MOSI__PORT HP
#endif
#ifndef GSPI_MASTER_MOSI__PIN
#define GSPI_MASTER_MOSI__PIN 27
#endif
#ifndef GSPI_MASTER_MOSI_LOC
#define GSPI_MASTER_MOSI_LOC 17
#endif

#ifndef GSPI_MASTER_MISO__PORT
#define GSPI_MASTER_MISO__PORT HP
#endif
#ifndef GSPI_MASTER_MISO__PIN
#define GSPI_MASTER_MISO__PIN 26
#endif
#ifndef GSPI_MASTER_MISO_LOC
#define GSPI_MASTER_MISO_LOC 22
#endif

#ifndef GSPI_MASTER_SCK__PORT
#define GSPI_MASTER_SCK__PORT HP
#endif
#ifndef GSPI_MASTER_SCK__PIN
#define GSPI_MASTER_SCK__PIN 25
#endif
#ifndef GSPI_MASTER_SCK_LOC
#define GSPI_MASTER_SCK_LOC 1
#endif

#ifndef GSPI_MASTER_CS0__PORT
#define GSPI_MASTER_CS0__PORT HP
#endif
#ifndef GSPI_MASTER_CS0__PIN
#define GSPI_MASTER_CS0__PIN 28
#endif
#ifndef GSPI_MASTER_CS0_LOC
#define GSPI_MASTER_CS0_LOC 5
#endif

#endif /* PIN_CONFIG_H */

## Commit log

2025-09-04 Add WiFi 6 board fw/hw and python API
2025-09-07 Clean the folder structure
    [2199230-5.PcbLib, 2199230-5.SchLib, 2450BP15E0100E.PcbLib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]
2025-09-07 WIFI6: Clean libraries and output files
    [2199230-5.PcbLib, 2199230-5.SchLib, 2450BP15E0100E.PcbLib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]
2025-09-07 WIFI6: Update prj file
    [wius_hardware.PrjPcb]
2025-09-08 PY: Precompile LL drivers
2025-09-08 PY: Prevompile LL drivers
2026-09-30 Release v0.2.0
    [Bill of Materials-tinyprobe_power_fix(fabrication).xlsx, Bill of Materials-wius_hardware(mcu_1v8_from_tinyprobe).xlsx, connectors.SchDoc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]
2026-10-01 docs: Update PCB project URLs
2026-11-03 hardware: errata for acquisition board R1-R32 MPN
    MPN part number doesn't match schematics: BOM lists ERJ-1GNF2000C (200 Ω) for R1–R32, schematic and description say 50 Ω.
    Claude-Session: https://claude.ai/code/session_011C6ckwJSTWwKSLZqbxE2jr
2026-11-05 hardware: R1-R32 erratum, 200 Ω is the value used (ETH confirmed)
    ETH confirmed the acquisition boards were built with ERJ-1GNF2000C
    (200 Ω); the 50 Ω in the schematic symbol and BOM description is the
    stale text. Reword the erratum accordingly instead of recommending
    49.9 Ω.
    Claude-Session: https://claude.ai/code/session_011C6ckutN5j8hUjSdgWwzcc
2026-11-09 add missing gerber files for wifi frontend board
